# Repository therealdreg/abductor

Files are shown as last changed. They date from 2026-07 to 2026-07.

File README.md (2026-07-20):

# Abductor

An adapter board that lets you run CW312-format (card-edge) targets on the ChipWhisperer CW308 UFO.
Discussion and questions on the NewAE forum: https://forum.newae.com/t/abductor-a-cw312-to-cw308-ufo-adapter-board/6514

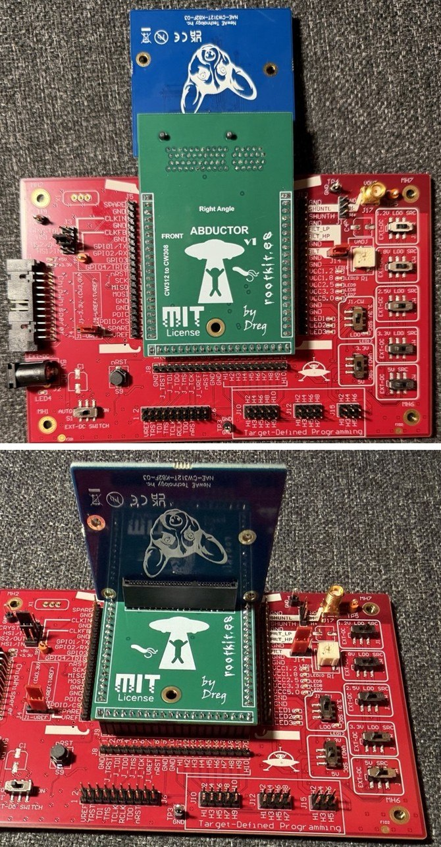
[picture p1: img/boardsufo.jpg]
The Abductor on a CW308 UFO


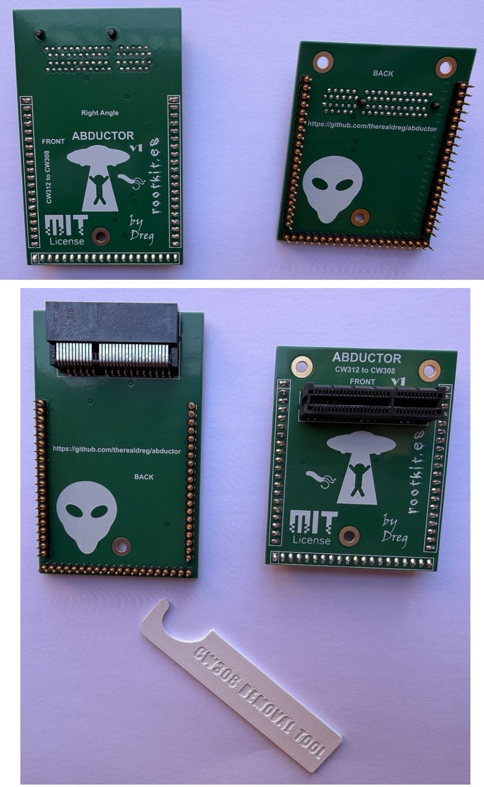
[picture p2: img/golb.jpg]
The Abductor board


There are two versions, one with a right-angle connector and one without. A dedicated target board
designed for one specific use case is usually preferable; when that is not practical, or simply not
possible, this adapter is a low-cost alternative.

Tip: to pull boards off the CW308 UFO without stressing or damaging the PCB, I use a 3D-printed removal
tool: https://github.com/therealdreg/removal_tool_cw308_ufo_chipwhisperer

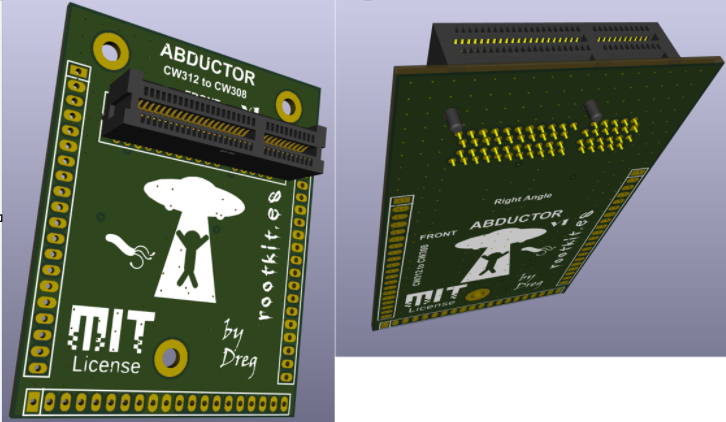
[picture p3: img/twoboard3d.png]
3D renders of the two Abductor variants: straight on the left, right-angle on the right


## Scope and limitations (please read first)

> I am an enthusiast, not a professional hardware or side-channel engineer. This board and its
> documentation are shared in case they are useful to someone, but they may contain mistakes, imprecise
> wording, or design choices a specialist would make differently. Treat everything here as an informal
> engineering log written in good faith, not a datasheet or a qualified test report. Before
> manufacturing the board or depending on it for anything important, review the KiCad source and the
> gerbers yourself. Corrections, reviews and feedback are genuinely welcome.
>
> Every result below comes from a single operator on a single bench, using one physical specimen of each
> board (one unit of each Abductor variant, standard and Right-Angle), one ChipWhisperer Husky Plus, and
> one of each target (CW312T-SAM4S, CW312T-iCE40UP, CW312T-K82F), at chipwhisperer commit `3c8e4347` (see
> the test bench). Most quantitative figures (SNR, TVLA t, |rho|, glitch bypass rates) are single runs
> and carry run-to-run and re-assembly variance that was not independently characterized here unless a
> sample count says otherwise; they are not multi-unit or multi-operator averages. Comparative words used
> throughout ("comparable", "consistent with", "no measurable difference") describe the specific sessions
> recorded here, not a general guarantee about the hardware. Where a result was inconclusive or a method
> was circular, it is flagged as such rather than smoothed over. On the whole, after the broad (if mostly
> single-run) testing below, I consider the electrical design validated for my own use and good enough
> for what I need it to do.

## How it works

The CW308 UFO and the CW312 target family use different physical interfaces. The UFO expects targets on
its 0.1-inch pin-header target sockets, while CW312 boards plug into a card-edge slot. The Abductor
bridges the two: it exposes the UFO target-header footprint on one side and a CW312 card-edge socket on
the other, and handles the signal mapping in between, so a CW312 target that uses the standard card-edge
interface should mount and run on the UFO. For the 1.00 mm CW312 edge the board uses a compatible Samtec
PCIE-series socket (part numbers and rationale are in the bill of materials).

Fitting the UFO theme, the name captures the idea: the UFO abducts the CW312 target and pulls it in so
it can run on the CW308 platform.

## Building the board

Everything needed to fabricate a board: the KiCad sources, the stackup and gerbers, the parts, and a note
on the small target-board trim the straight variant calls for.

### KiCad v10 sources

This is not a KiCad project I work in regularly, so please review the source files before relying on
them for manufacturing. Two plugins are used:

- ViaStitching: https://github.com/dobredanielstelian/ViaStitching (a KiCad 10 port of JS Reynaud's
  via-stitching plugin, `jsreynaud/kicad-action-scripts`)
- easyeda2kicad: install with `pip install easyeda2kicad` (uPesy's tool; output targets KiCad v6+)

The two connector footprints are imported with easyeda2kicad:

```
python -m easyeda2kicad --full --lcsc_id=C4597619 --output "C:\\path\\to\\project" --project-relative --overwrite

python -m easyeda2kicad --full --lcsc_id=C4571870 --output "C:\\path\\to\\project\\right_angle" --project-relative --overwrite
```

(LCSC `C4597619` = Samtec PCIE-064-02-F-D-TH, `C4571870` = Samtec PCIE-064-02-F-D-RA; these match the
bill of materials below.)

### PCB and gerbers

Six layers, ENIG finish. This many signals (power and shunt sensing, the HS2 clock, serial, the
crowbar/VOUT glitch path, the JTAG/SWD debug lines, the trigger, the LEDs and GPIO) route more
comfortably on six layers, which give a continuous ground plane, a power layer split into islands for the
several rails, and shorter return paths. I chose six layers for that routing headroom, not because the
data proves them necessary: at ~7 MHz the signal-integrity upside should
be small, and the A/B comparison in the results below does not show the adapter improving on a direct
connection. Whether four layers would perform the same I cannot say, since I never built one to compare.
I chose ENIG for flat, uniform pads under the 1.00 mm fine-pitch Samtec socket; this board has no
gold-finger edge of its own, so a cheaper HASL finish would most likely also work. I ordered both variants
as six-layer ENIG prototypes from JLCPCB (https://jlcpcb.com/quote), five pieces of each, and the boards
were more than suitable for the testing that follows. They came back to this spec:

| JLCPCB parameter | Value |
|---|---|
| Base material | FR-4, TG135 |
| Layers | 6 |
| Dimensions | 54 mm × 67 mm |
| Thickness | 1.6 mm |
| Outer / inner copper | 1 oz / 0.5 oz |
| Surface finish | ENIG, 1 µin gold (1U″) |
| Solder mask / silkscreen | Green / white, ink-jet |
| Via covering | Epoxy filled and capped |
| Min via | 0.3 mm hole, 0.4 to 0.45 mm diameter |
| Electrical test | Flying-probe, full |
| Appearance quality | IPC Class 2 |
| Outline tolerance | ±0.2 mm |

The value impressed me: for a six-layer, ENIG, flying-probe-tested board ordered in a small five-off
prototype quantity, the quality came out far better than I expected for such an inexpensive low-volume run,
and I was genuinely impressed by what came back.

Schematic: 

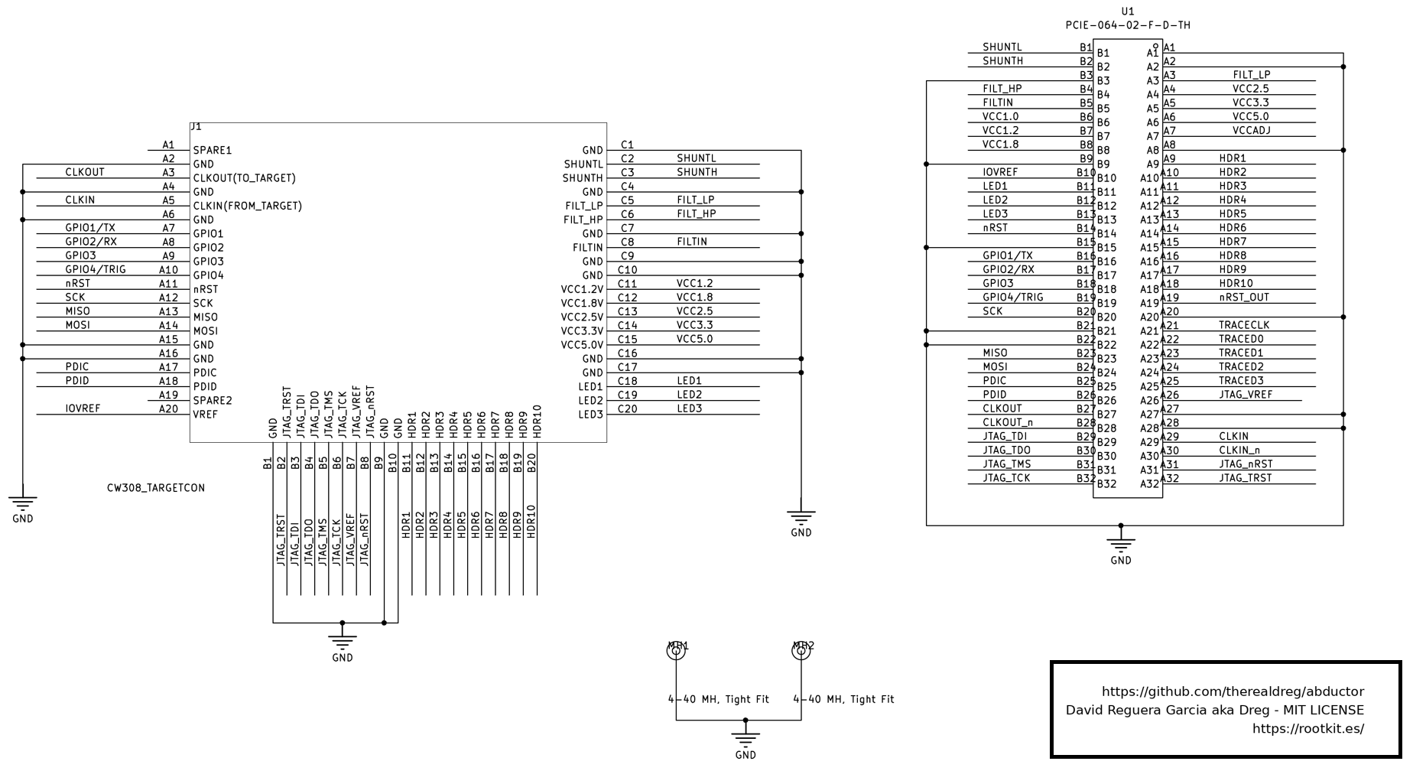
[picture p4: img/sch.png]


Gerbers:

- Straight version: [prj/gerber.zip](prj/gerber.zip)
- Right-angle version: [prj/right_angle/gerber.zip](prj/right_angle/gerber.zip)

### Bill of materials

NewAE does not publish a connector part number for the 1.00 mm CW312 card edge (the CW313 documentation
only calls it the "cost-optimized CW312 card edge connector"), so the parts below are a compatible
selection I chose, not an official NewAE specification.

**Card-edge socket, straight: Samtec PCIE-064-02-F-D-TH.** 1.00 mm pitch, 64-position (mechanically the
length of a PCIe x4 slot), through-hole card-edge socket from Samtec's PCIe-connector series. It is used
here purely for its mechanical fit to the 1.00 mm CW312 card edge; the connector's PCIe signaling rating
is not relevant, since this edge carries DC rails and a ~7 MHz clock, not a PCIe link. Mouser: https://www.mouser.es/ProductDetail/Samtec/PCIE-064-02-F-D-TH?qs=iT52DjcXudu3X3%2FATBSy9g%3D%3D

**Card-edge socket, right-angle: Samtec PCIE-064-02-F-D-RA.** Right-angle version of the same 1.00 mm
pitch, 64-position Samtec card-edge socket (same PCIe-connector series, again used only for mechanical
fit). Mouser: https://www.mouser.es/ProductDetail/Samtec/PCIE-064-02-F-D-RA?qs=92ilVni64gwDtfpZKan9%2FQ%3D%3D

**Male header: Preci-dip 800-10-020-10-001101.** 20-pin, 2.54 mm machined pin strip. Mouser: https://www.mouser.es/ProductDetail/437-8001002010001101

**Female socket strip: Preci-dip 801-87-020-10-001101.** 20-pin, 2.54 mm machined socket strip; the same
20-pin header NewAE specifies for the CW308. Mouser: https://www.mouser.es/ProductDetail/437-8018702010001101

### Target-board clearance (straight variant only)

On the **straight** Abductor, a small corner of the ChipWhisperer CW312 target board fouls the adapter
when the target is seated, so that corner of the **target board** has to be trimmed off. The photos below
show it on a CW312T-K82F target: the corner is nipped with flush cutters and the edge sanded, away from
the target's mounting hole. This is not an Abductor design flaw and cannot be designed out of the adapter,
because the collision is with the official ChipWhisperer target boards, which are fixed products you
cannot redesign; on the straight variant you simply remove that small corner from each target once. It is
a minor, one-time step, not a drama. The **Right-Angle** Abductor does not need it: its right-angle
connector seats the target clear of the adapter, so no target has to be trimmed.

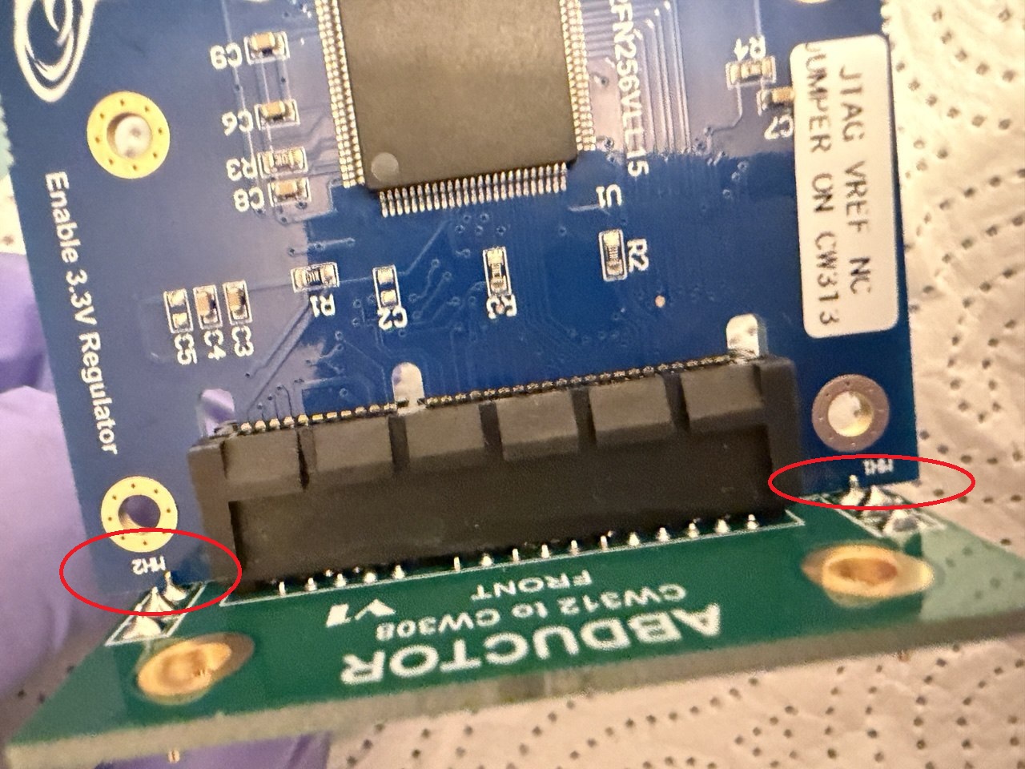
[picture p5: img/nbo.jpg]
The corner of the CW312 target board that fouls the straight Abductor when seated


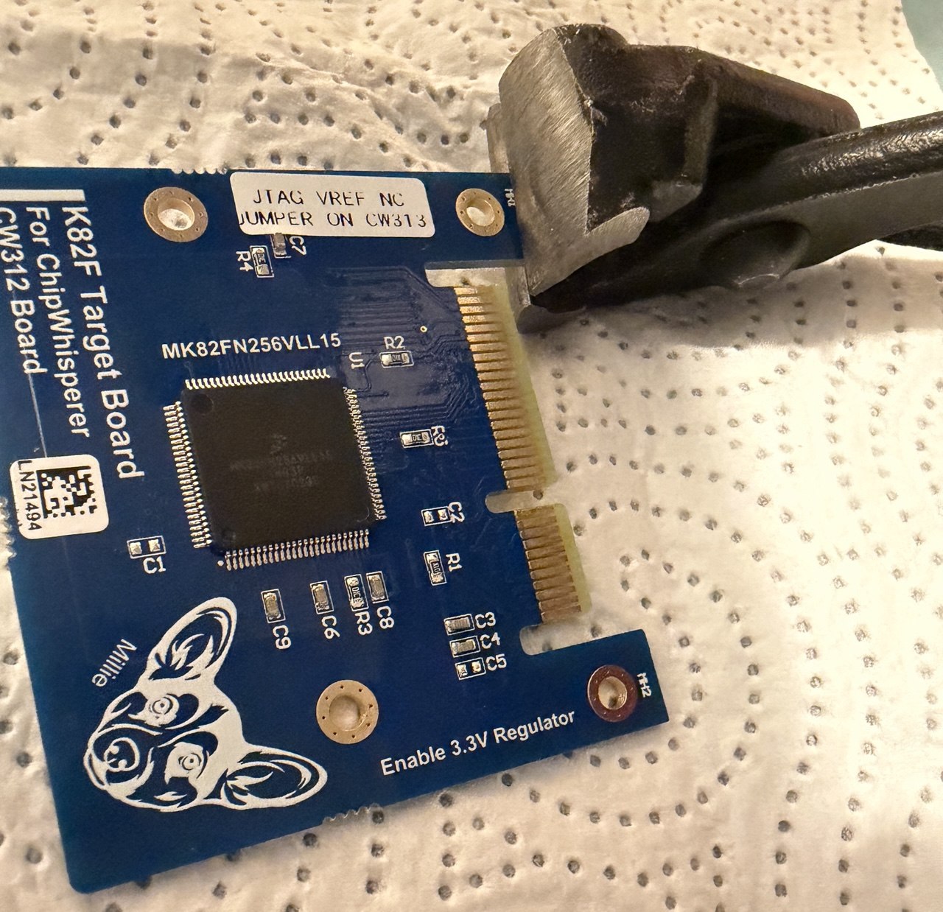
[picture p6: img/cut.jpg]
Trimming that corner off the CW312 target board with flush cutters


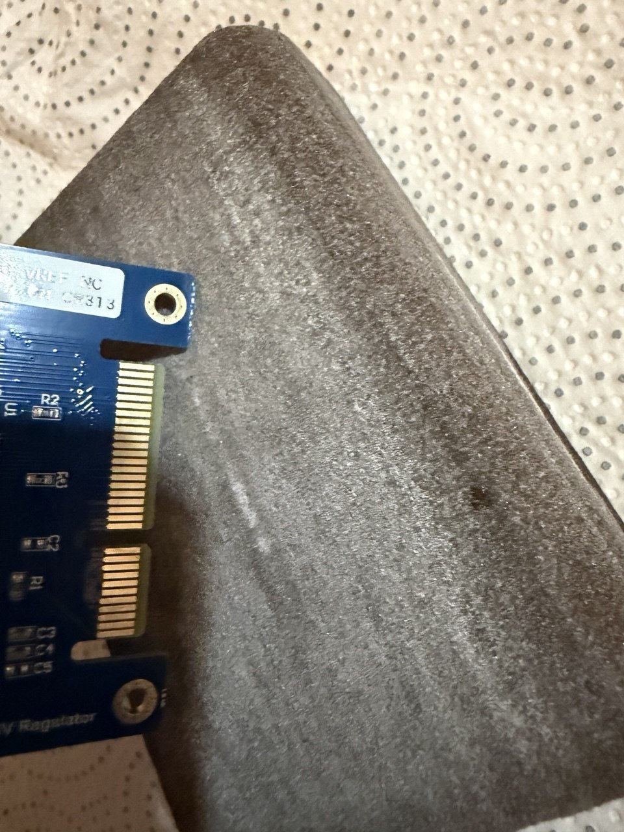
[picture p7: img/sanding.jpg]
The sanded edge of the trimmed target board


This is roughly how much of the target-board corner to remove:

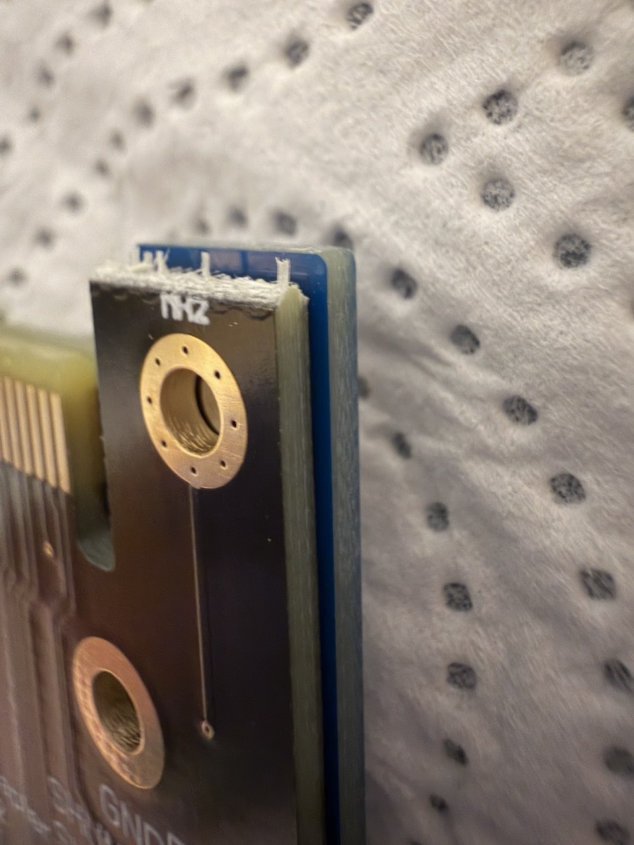
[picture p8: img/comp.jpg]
How much of the target-board corner to remove


---

## ChipWhisperer validation

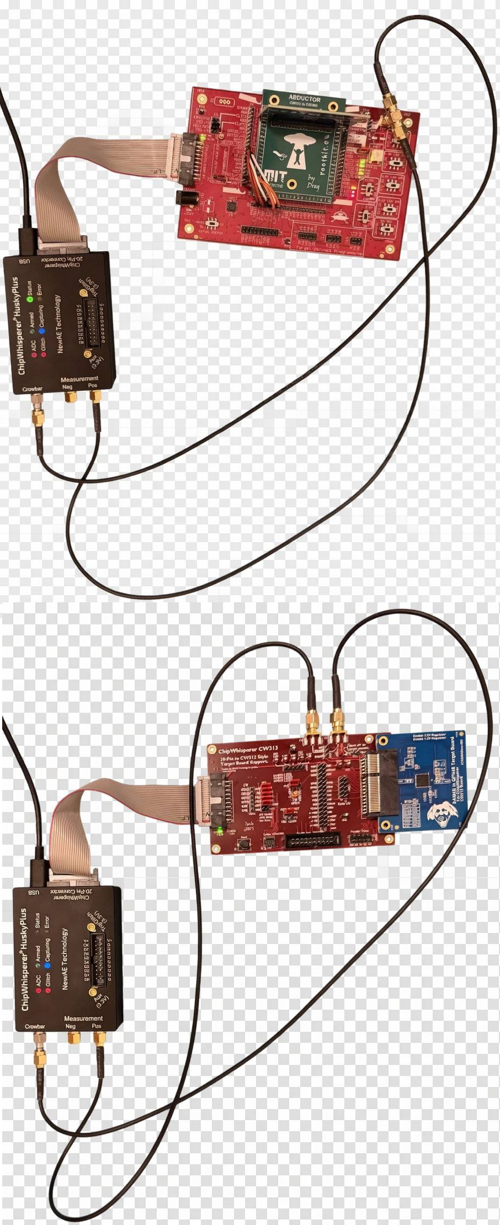
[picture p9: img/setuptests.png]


The rest of this document is my own functional testing of the board on real ChipWhisperer hardware, run
one demo at a time through the adapter. The aim is to show that the adapter carries the signals each demo
needs and produces valid side-channel data, not to reproduce the reference notebooks pixel for pixel.
Please read the scope and limitations above before taking any number as more than a single-bench
observation.

- **Date:** 2026-07-18 (standard Abductor, iCE40, K82F); 2026-07-19 (Right-Angle variant).
- **Setup under test:** the **standard Abductor** and, separately, the **Right-Angle** variant, each on
  the CW308 UFO with a CW312T-SAM4S target and a Husky Plus (the full bench is tabulated below).
- **Method:** one demo at a time, each verified before moving on, following the course order starting
  with `sca101`.

## Test bench

Every number in this document comes from this one bench: the hardware below, driving the software
environment below.

| Hardware | Detail |
|---|---|
| Capture | ChipWhisperer **Husky Plus**, USB `2b3e:ace6`, SN `50203220573555303230333230313036` |
| Husky firmware | FW `1.2.0`, FPGA build `2026-05-22 12:13` |
| Carrier | CW308 **UFO** |
| Adapter | **Abductor** CW312 to CW308, **standard variant (non-right-angle)** |
| Target | **CW312T-SAM4S** (Microchip / ex-Atmel SAM4S, ATSAM4S2, Arm Cortex-M4 without FPU), `PLATFORM=CW312_SAM4S` |
| Target clock | `scope.default_setup()` requests 7.37 MHz on HS2 (`scope.io.hs2='clkgen'`); the Husky's clock generator produces 7.363636 MHz (consistent with the `adc_mul=4` ADC rate 29.454545 MHz) |
| ADC | 29.454545 MHz (`adc_mul=4`), 12 bit |

HS2 is the ChipWhisperer high-speed clock output; on the CW308 it reaches the target CLKIN through the
UFO's clock routing.

| Software | Version / value |
|---|---|
| OS | **Ubuntu 26.04 LTS**, kernel `7.0.0-28-generic`, x86_64 |
| chipwhisperer repo | branch `develop`, commit **`3c8e4347507376d88f2e072fd39df28b380dd713`** (`3c8e4347`, 2026-06-17) |
| commit subject | `Wait after setting trace/UARTTtrigger.fe_clock_src` |
| `jupyter` submodule (notebooks) | `fe7e2aa1585798c3a5a6b247f231abe2e2b4a2cd` |
| chipwhisperer package | `6.0.0` (editable install) |
| Python (venv) | `3.12.13`, created with `uv 0.11.29` |
| Python (system) | `3.14.4`, not used because `numpy 1.26.4` ships no 3.14 wheels and did not build from source in this environment |
| numpy | `1.26.4` |
| ARM toolchain | xpack `arm-none-eabi-gcc 13.3.1` |
| SimpleSerial | `SS_VER_1_1` (firmware default for the base target) |
| SAM4S programmer | SAM-BA (`cw.programmers.SAM4SProgrammer`, erase pin `pdic`) |

## Results summary: Abductor vs Right-Angle vs CW313

The same test suite was run through three setups with the same CW312T-SAM4S target and Husky Plus: the
standard **Abductor** (Husky -> CW308 UFO -> Abductor -> SAM4S), a second **Right-Angle Abductor**
hardware variant, and the SAM4S in its native **CW313** baseboard directly (no adapter). The **Abductor
RA** column is that right-angle variant: its PCB traces run a little longer and are routed differently,
so it is a useful check that the extra routing does not degrade anything. Two further targets, a
**CW312T-iCE40UP** FPGA and a **CW312T-K82F** hardware crypto accelerator, were also run through every
setup as completely different target classes; each non-SAM4S target was moved from the Abductor into the
CW313 directly for its reference run.

Abductor evidence is in `validation/img/` and the `*_dump.txt` files; the CW313 reference is in
`validation/img/cw313/`, `validation/img/*_cw313.png` and `*_cw313_dump.txt`. Every capture script accepts
a `cw313` argument to reproduce the reference run.

| Test | Metric | Abductor | Abductor RA | CW313 direct | Verdict |
|---|---|---|---|---|---|
| Bring-up | traces / serial echo | 10/10 · 10/10 | 10/10 · 10/10 | 10/10 · 10/10 | same |
| Bring-up | mean power p2p | 0.57 | 0.68 | 0.62 | ~same |
| CPA (AES) | full key | yes | yes | yes | same |
| CPA | traces to rank 0 (single run) | 30 | 30 | 30 | same (see note) |
| DPA (AES) | full 16-byte key | yes | yes | yes | same |
| Password SPA | recovered | `h0px3` | `h0px3` | `h0px3` | same |
| Password SPA | winner margin | 22x to 24x | 23x to 25x | 23x to 24x | comparable |
| SNR | peak (linear / dB) | 14.1 / 11.5 dB | 14.0 / 11.5 dB | 16.7 / 12.2 dB | CW313 ~18% higher (linear); single estimate each, small degradation not excluded |
| TVLA | max \|t\| (threshold 4.5) | 60.7 | 59.5 | 60.7 | comparable |
| GPIO3 | TIO3 toggles | yes | yes | yes | same |
| SWD debug | DPIDR / Chip ID | `0x2ba01477` / `0x288b07e1` | `0x2ba01477` / `0x288b07e1` | `0x2ba01477` / `0x288b07e1` | identical |
| Full JTAG | TAP IDCODE | `0x4ba00477` | `0x4ba00477` | `0x4ba00477` | identical |
| Voltage glitch HP | optimum (width, offset, ext) | (1950, 2480, 129) | (2000, 2450, 129) | (1950, 2460, 129) | same ext (129); offset differs by ~1 step |
| Voltage glitch HP | bypass rate | 49.5% (200-shot batch) | 90% (36/40 peak, 40 shots) | 40.5% (200-shot batch) | bypasses on all paths (RA is a 40-shot peak, not directly comparable to the 200-shot batch rates; the standard Abductor's comparable peak is 78% to 98%, see Fault injection) |
| Voltage glitch LP | crash vs repeat | rep1 clean, rep>=2 crash | rep1 clean, rep>=2 crash | rep1 clean, rep>=2 crash | same threshold |
| Clock glitch | faults the SAM4S | yes | yes | yes | same |
| LED1/2/3 | blink in sequence | yes | yes | yes | same |
| Memory dump | crowbar send-loop | 601-byte @ (2000, 2480, 2122) | 510-byte @ (1900, 2200, 88), secret leaked | 510-byte @ (2000, 2480, 2122) | same class of fault (probabilistic point; dump length varies) |
| iCE40 AES | known-answer `AES(0,0)` | `66e94bd4...` | `66e94bd4...` | `66e94bd4...` | identical |
| iCE40 CPA | traces to full key | 3000 | 3000 | 3000 | same (single-run convergence) |
| iCE40 TVLA | max \|t\| (threshold 4.5) | 85.0 | 85.8 | 89.3 | comparable |
| iCE40 DFA | full key (round-8, phoenixAES) | 16/16 | 16/16 | 16/16 | same |
| K82F KAT | `AES(2b7e..,00..0f)` | `50fe67cc...` | `50fe67cc...` | `50fe67cc...` | identical |
| K82F TVLA | max \|t\| (threshold 4.5) | 100.6 | 96.0 | 65.8 | all ≫ 4.5 at 8k traces each (large single-run spread) |
| K82F CPA | byte-0 leakage \|rho\| | ~0.10 | ~0.10 | ~0.10 (0.095) | ~same (each \|rho\| has SE ~0.005; the exact tie is coincidental) |
| K82F CPA | full AES key | not recovered (1/16, rigorous disjoint-set) | not recovered (0/16) | not recovered (0/16) | consistent with target, not adapter (single control run; the 1/16 is at most one byte, not a full-key break) |

Verdict key: *identical* = bit/value-exact match for fixed digital quantities (IDCODEs, KATs). *~same* =
point estimates whose difference is within (or smaller than) the available scatter, so a small effect is
neither confirmed nor excluded (SNR, |rho|, p2p). *comparable* = same order of magnitude, differences
consistent with run-to-run variation (TVLA t, margins). *same* = same qualitative pass/fail. Two
result-specific notes on the table: *traces to rank 0* is a single-run, data-dependent convergence count
on a coarse trace grid, not a bit-exact constant and not a guessing-entropy average; it landed at 30 on
all three paths here but can vary run-to-run (see Side channel). For *K82F full AES key*, the mmCAU is an
unprotected accelerator that first-order CPA did not break on any path; the single byte recovered under
the rigorous criterion on the Abductor (1/16, vs 0/16 on the other two) is a marginal one-byte result at
the edge of the method's sensitivity, not a full-key break (see the K82F target).

**Conclusion.** Within this setup and test set, no test resolved a difference between the Abductor and
the SAM4S running directly in a CW313 baseboard beyond single-run scatter, the one exception being the
SNR point estimate, which was in fact slightly *higher* on the direct CW313 path (16.7 vs 14.1 linear;
about 0.7 dB). So this run gives no evidence that the Abductor improves the signal, and with one estimate
per path a small degradation cannot be excluded either (see Signal coverage and integrity). Otherwise the
adapter carried the demonstrated portion of the suite (side channel, fault injection, debug, I/O) with
results consistent with the direct connection: CPA recovers the full key in the same 30 traces; TVLA
max |t| came out at 60.7 on both paths (an exact match to three significant figures that is coincidental,
see Signal coverage and integrity); the fixed debug IDs match bit-for-bit; the glitch optimum lands at the same
ext_offset (129); the 200-shot bypass rates (49.5% Abductor, 40.5% CW313) differ by less than the
measurement can resolve (see Fault injection); and the memory-dump fault lands at the same parameters.
The **Right-Angle** variant behaved the same way, reproducing every key outcome despite its longer,
differently-routed traces (SNR 14.0 vs 14.1, TVLA 59.5 vs 60.7, CPA full key in the same 30 traces,
matching DPIDR and JTAG IDCODE, glitch at the same ext_offset 129, and a memory dump that leaked the
secret). The two other targets stretch the range further: through the Abductor, the iCE40 FPGA fell to
both a hardware-AES CPA and a full `phoenixAES` DFA, while the K82F mmCAU accelerator resisted the
first-order CPA tried here on every path alike. Per-test detail and evidence follow below.

## Primary target: CW312T-SAM4S

The SAM4S is the primary target and gets the deepest workout: a bring-up smoke test, the full `sca101`
side-channel walkthrough, `fault101` voltage and clock glitching, a JTAG/SWD debug takeover, and a
pin-by-pin coverage and signal-integrity check. Each subsection exercises a different set of signals the
Abductor has to route.

### Bring-up: signal chain validation

A smoke test that builds `simpleserial-base`, flashes it over SAM-BA, and captures traces. Each row
exercises a distinct path the Abductor has to route. Script: `validation/scripts/smoke_bringup.py`.

| # | Test | Abductor path exercised | Status | Metric |
|---|---|---|---|---|
| 0 | Connect to Husky Plus | n/a (scope only) | ✅ | `cwhuskyplus`, FW 1.2.0 |
| 1 | Build SAM4S firmware | n/a (host build) | ✅ | `simpleserial-base-CW312_SAM4S.hex`, ROM 2.17% of 128 KB |
| 2 | Flash over SAM-BA (ERASE=`pdic`, `nrst`) | control and reset lines | ✅ | program plus verify OK in 5.0 s |
| 3 | Bidirectional UART (echo of `p` command) | serial TX and RX | ✅ | 10/10 echoes correct |
| 4 | Trigger and capture | trigger and sync | ✅ | 10/10 traces, 5000 samples each |
| 5 | Clock and power measurement | HS2 clock plus shunt/SMA | ✅ | mean per-trace p2p 0.57, global sample std 0.14, clean clock cycles |

The Abductor routed clock, power, serial, ERASE and NRST correctly in this run. The full signal chain
(Husky Plus -> CW308 UFO -> Abductor -> SAM4S) is operational.

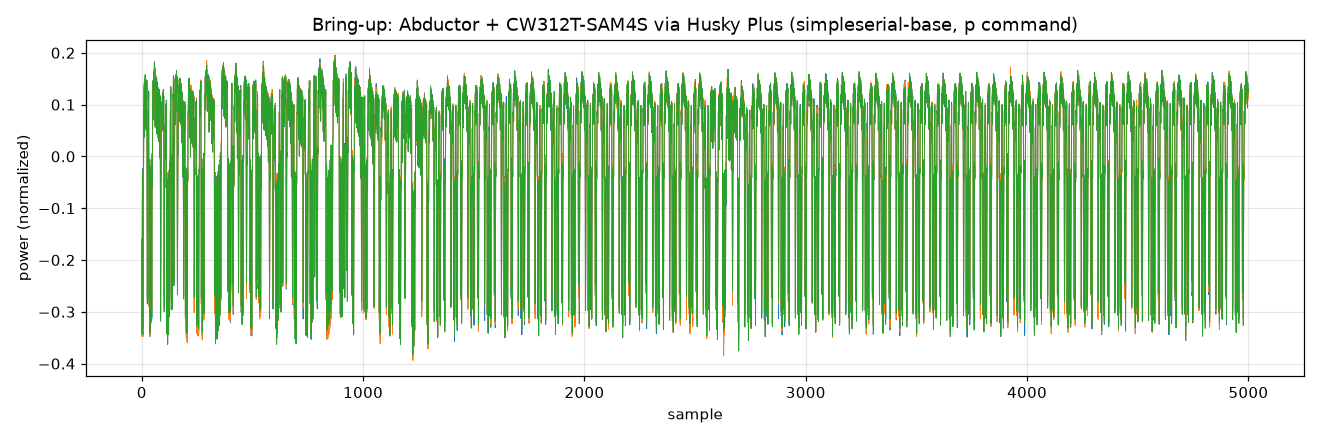
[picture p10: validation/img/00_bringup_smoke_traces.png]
Bring-up power traces


### Side channel (sca101 walkthrough)

The `sca101` course builds up from timing to a full AES key recovery. Every hardware lab passed; the
software-only labs are skipped and marked as such.

| Lab | Title | Firmware | Status |
|---|---|---|---|
| 2_1A | Instruction Power Differences | simpleserial-base | ✅ Pass |
| 2_1B | Power Analysis for Password Bypass | basic-passwdcheck | ✅ Pass |
| 3_1 | Large Hamming Weight Swings | simpleserial-aes (TINYAES128C) | ✅ Pass |
| 3_2 | Recovering Data from a Single Bit | n/a | ⏭️ Skipped (software-only, no hardware) |
| 3_3 | DPA on a Firmware AES Implementation | simpleserial-aes (TINYAES128C) | ✅ Pass (full key) |
| 4_1 | Power and Hamming Weight Relationship | n/a | ⏭️ Skipped (low-impact stepping stone) |
| 4_2 | CPA on a Firmware AES Implementation | simpleserial-aes (TINYAES128C) | ✅ Pass (full key, 30 traces) |
| 4_3 | ChipWhisperer Analyzer CPA Attack | simpleserial-aes | ⏳ Pending |
| 5_1 | ChipWhisperer CPA Attacks in Practice | simpleserial-aes | ⏳ Pending |
| 6_4 | Jittery Triggering on UART | simpleserial-base | ⏳ Pending |

Legend: ✅ pass · ⏳ pending · ⚠️ pass with notes · ❌ fail · ⏭️ skipped (not a hardware test)

#### Lab 2_1A: Instruction Power Differences

Different instruction blocks were inserted between `trigger_high()` and `trigger_low()` in
`simpleserial-base`, then built, flashed and captured. The execution cost of each block is read directly
from the trigger duration (`scope.adc.trig_count`). This counter is in ADC samples, and with `adc_mul=4`
there are 4 samples per core clock cycle, so the counts below are ADC samples (roughly 4x the core-cycle
count), not core cycles. Script: `validation/scripts/lab_2_1A.py`.

| Instruction block | Trigger duration (ADC samples) | Cost vs baseline |
|---|---|---|
| baseline (empty) | 492 | reference |
| 20x `A *= 2` (unrolled multiply) | 992 | +500 (about 25 ADC samples, ~6 core cycles, per volatile statement) |
| loop x20 `A *= 2` (multiply) | 2132 | +1640 (about 82 ADC samples, ~20 core cycles, per iteration) |
| loop x20 `A /= 3` (integer divide, multi-cycle) | 2276 | +1784 (144 more than the multiply loop) |

Findings:

- The sample count was identical across all 15 captures (min equals max), as expected for a
  deterministic trigger counter, and consistent with the count being read back without corruption
  through the Abductor.
- The unrolled block adds a flat per-statement cost. The looped version costs far more than unrolling the
  same 20 multiplies; the extra cost is consistent with per-iteration loop overhead (the volatile counter
  load/store, compare and branch), though this measurement records only the total trigger duration and
  does not isolate those components individually.
- The divide loop is more expensive than the multiply loop. Here `A` is a `volatile long int`, so
  `A /= 3` is integer division, which is more work than the multiply either way: depending on the build
  optimization the compiler emits the multi-cycle Cortex-M4 `SDIV`, or, for a constant divisor like 3, a
  strength-reduced multiply-and-shift sequence. This measurement records only the total trigger duration
  and cannot distinguish the two, so it does not prove an `SDIV` executed; the higher cost is simply
  consistent with integer division costing more than the multiply.

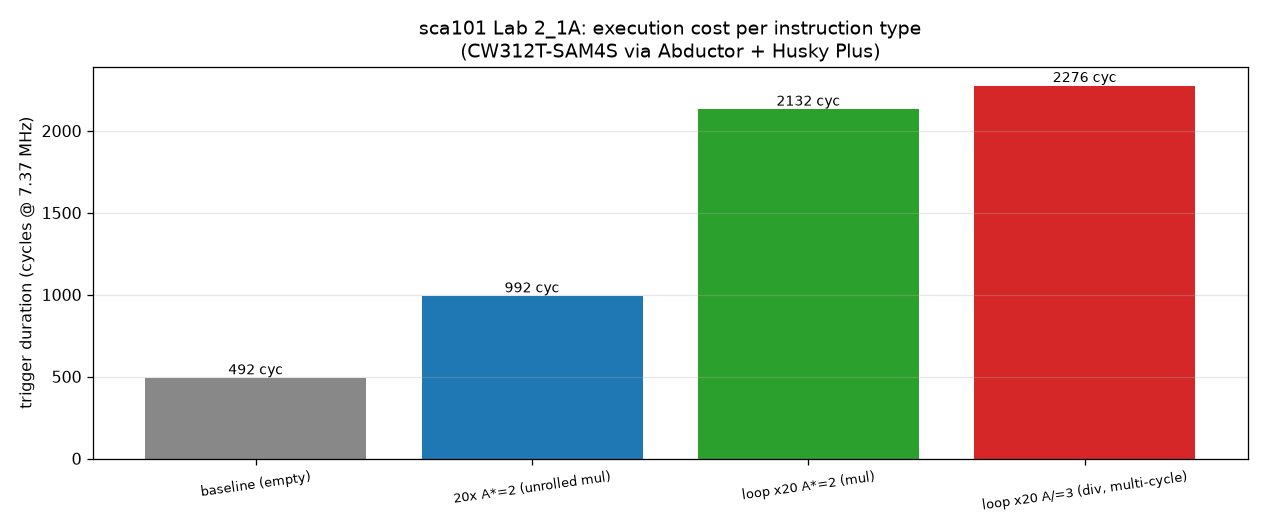
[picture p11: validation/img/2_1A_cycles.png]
Execution cost per instruction type


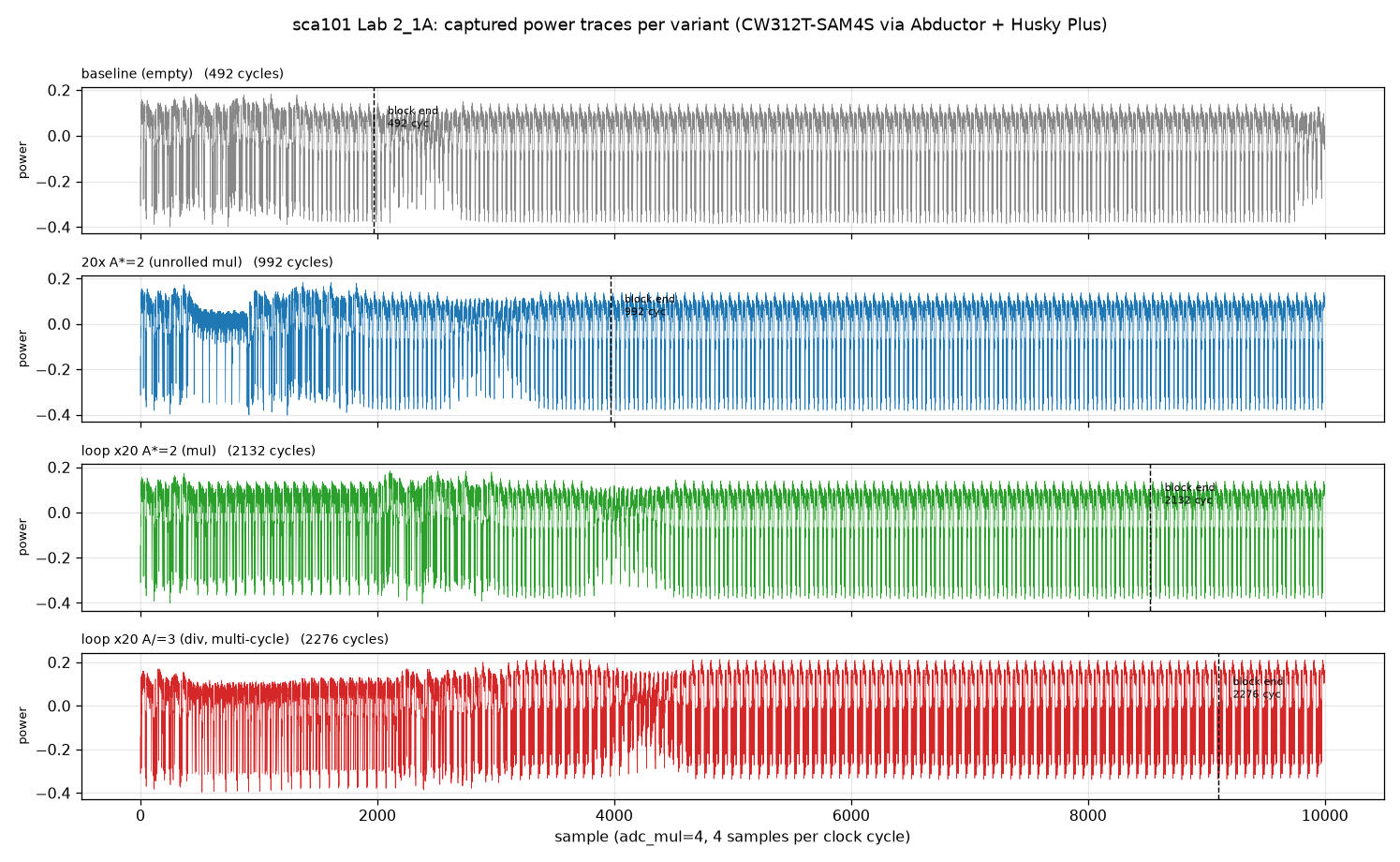
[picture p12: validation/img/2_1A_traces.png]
Captured power traces per variant


#### Lab 2_1B: Power Analysis for Password Bypass

`basic-passwdcheck` checks a fixed password (`h0px3`) one character at a time and bails on the first wrong
character. Each correct character runs one extra loop iteration, so the power trace stays active longer
before diverging. The attack captures one trace per candidate, scores it against a wrong reference with
SAD (sum of absolute differences), keeps the highest scoring character, then repeats for the next
position using the known prefix. Script: `validation/scripts/lab_2_1B.py`.

| Position | Recovered char | SAD (winner) | SAD (2nd best) | Margin |
|---|---|---|---|---|
| 0 | `h` | 286.6 | 11.9 | 24.0x |
| 1 | `0` | 284.6 | 12.4 | 22.9x |
| 2 | `p` | 280.3 | 12.7 | 22.1x |
| 3 | `x` | 274.5 | 12.4 | 22.1x |
| 4 | `3` | 301.7 | 12.3 | 24.4x |

Recovered password: **`h0px3`**, which matches the firmware constant. (Margins are computed from the
full-precision SAD values, so they may differ slightly from dividing the rounded columns shown here.)

The correct character wins each position by roughly 22x to 24x in SAD, a large and easily separable margin
on these single-trace-per-candidate captures. The divergence figure shows the correct and wrong
first-character traces overlapping until the compared byte, then splitting cleanly around sample 420. The
heatmap shows one bright cell per position, spelling out the password.

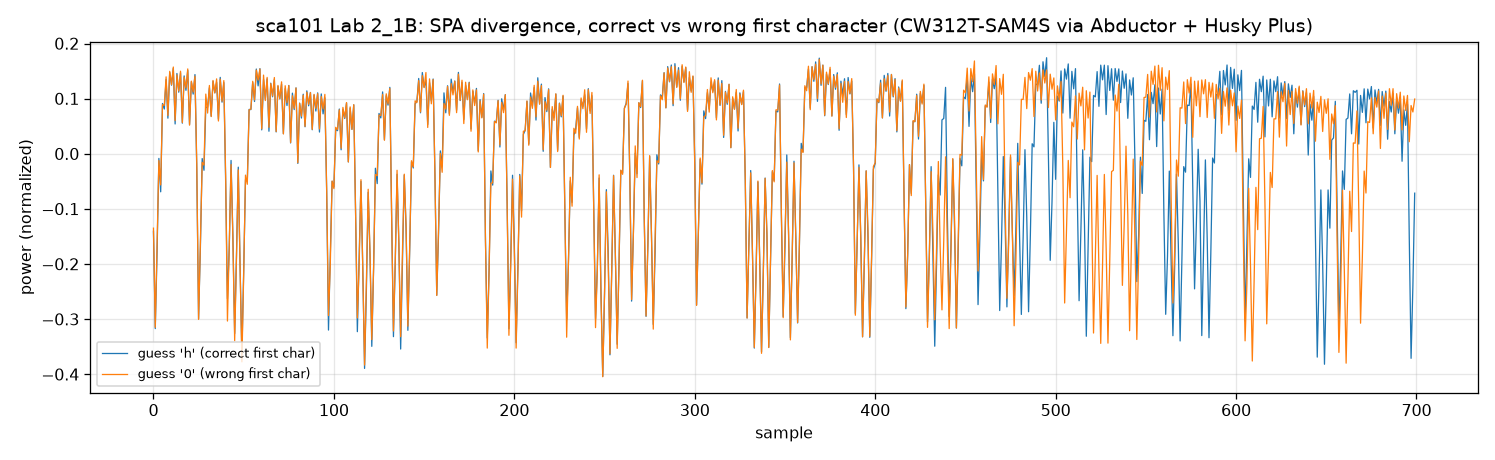
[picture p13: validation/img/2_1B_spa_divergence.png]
SPA divergence, correct vs wrong first character


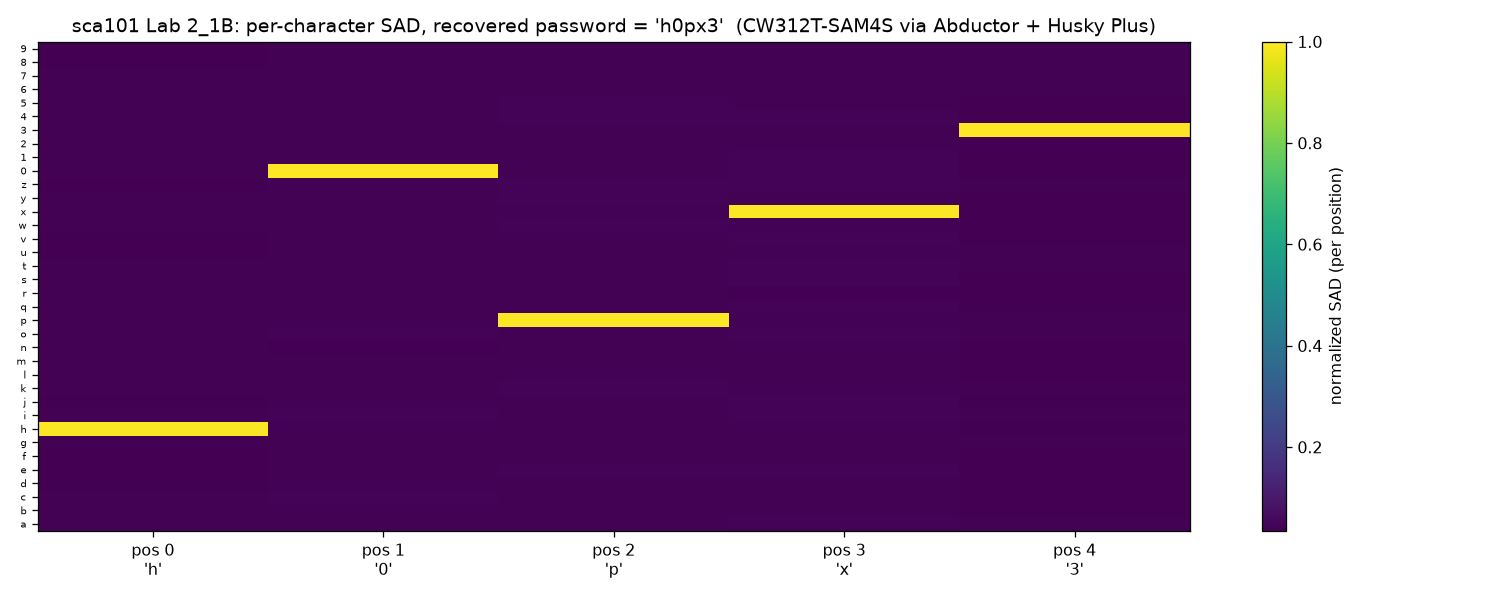
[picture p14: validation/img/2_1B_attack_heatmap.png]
Per-character SAD heatmap with the recovered password


#### Lab 3_1: Large Hamming Weight Swings

This lab shows the target's power depends on the data it manipulates, not only on the code path. With
`simpleserial-aes` (TINYAES128C) running a fixed key, 200 traces were captured while forcing plaintext
byte 0 to either `0x00` (Hamming weight 0) or `0xFF` (Hamming weight 8). In the script each trace's byte 0
is set to `0xFF` or `0x00` according to the parity of the original random byte, which gives a roughly even
split. Averaging each group and subtracting gives the data-dependent leak. Script:
`validation/scripts/lab_3_1.py`.

| Metric | Value |
|---|---|
| Traces | 200 (~100 at 0x00, ~100 at 0xFF, split by the parity of the random byte 0) |
| Peak difference | 0.0254 in magnitude at sample 528 (the value is negative, see the sign note below) |
| Noise floor (std of the difference trace away from the peak) | 0.0008 |
| Leak vs noise | peak difference ~32x the off-peak difference-trace std (informal single-run ratio, not an SNR) |

The difference of means is flat everywhere except a sharp spike at sample 528, where the target loads and
processes that byte. The spike is negative because ChipWhisperer measures across a shunt, so more power
reads as lower voltage, and `0xFF` (more bits set) draws more power than `0x00`. This is the same class of
data-dependent, Hamming-weight leakage that CPA on AES exploits (there through the Hamming weight of the
S-box output, `HW(SBox(pt XOR key))`, rather than the plaintext byte itself).

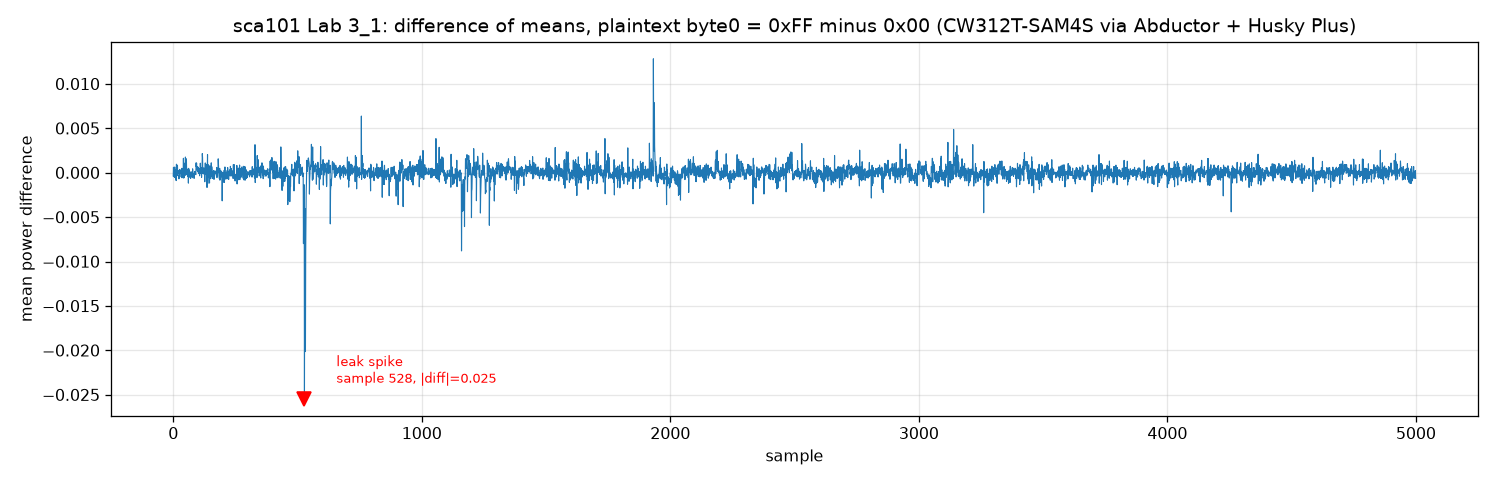
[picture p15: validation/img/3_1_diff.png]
Difference of means, 0xFF minus 0x00


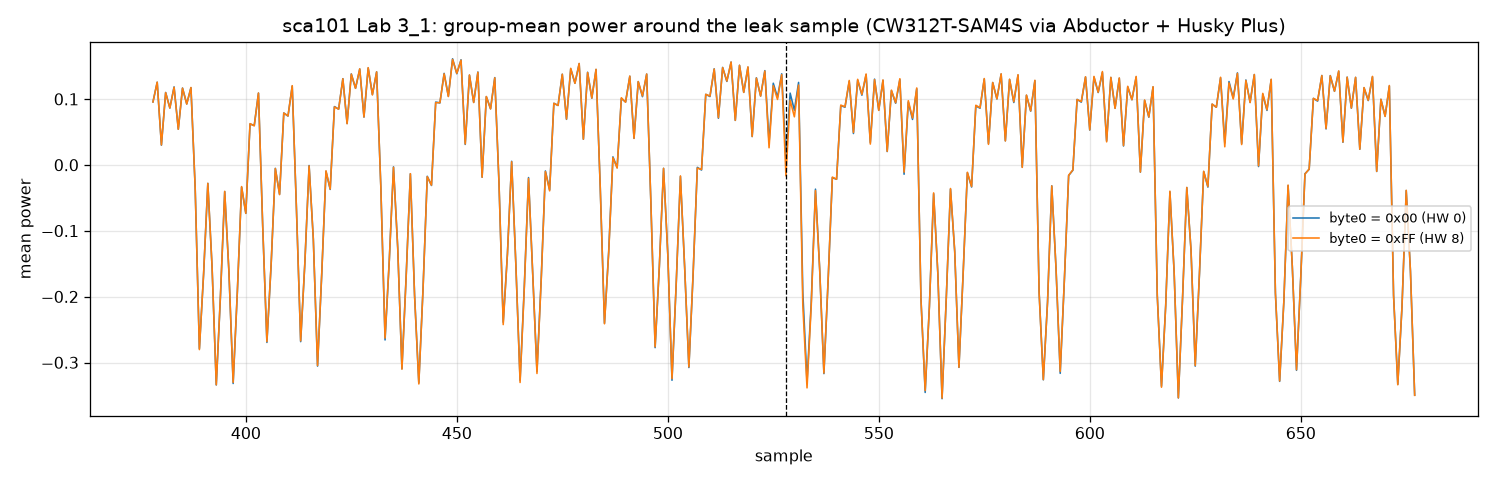
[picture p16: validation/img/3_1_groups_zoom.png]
Group-mean power around the leak sample


#### Lab 3_3: DPA on a Firmware AES Implementation

This is the first full key recovery in the suite: the complete AES-128 key was recovered from the captured
power traces. With `simpleserial-aes` (TINYAES128C) and a fixed key, 2500 traces were captured (about
119 traces/s) while sending random plaintexts. For each key byte and each of the 256 guesses, the traces
are split by bit 0 of `SBox(plaintext_byte XOR key_guess)` and the difference of the two group means is
computed. The guess whose difference-of-means trace peaks highest is taken as the key byte. Script:
`validation/scripts/lab_3_3.py`.

- Traces: 2500 (fixed key, random plaintext)
- Recovered key: `2b7e151628aed2a6abf7158809cf4f3c`
- Known key: `2b7e151628aed2a6abf7158809cf4f3c`
- Full key match: **yes, all 16 bytes**

For every byte the correct guess peak sits above the best wrong guess. For key byte 0 the correct guess
`0x2b` produces a sharp peak near sample 1900 while wrong guesses stay in the noise. The winner margin is
modest because single-bit DPA is noisier than CPA; the CPA lab below improves on this.

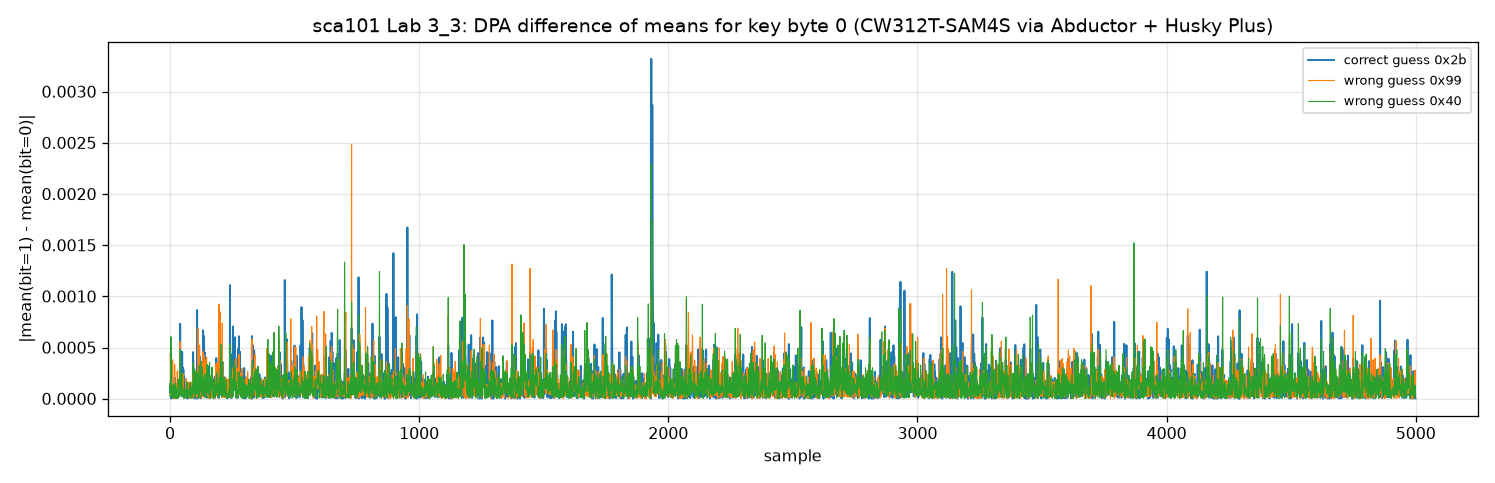
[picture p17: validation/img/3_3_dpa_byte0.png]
DPA difference of means for key byte 0


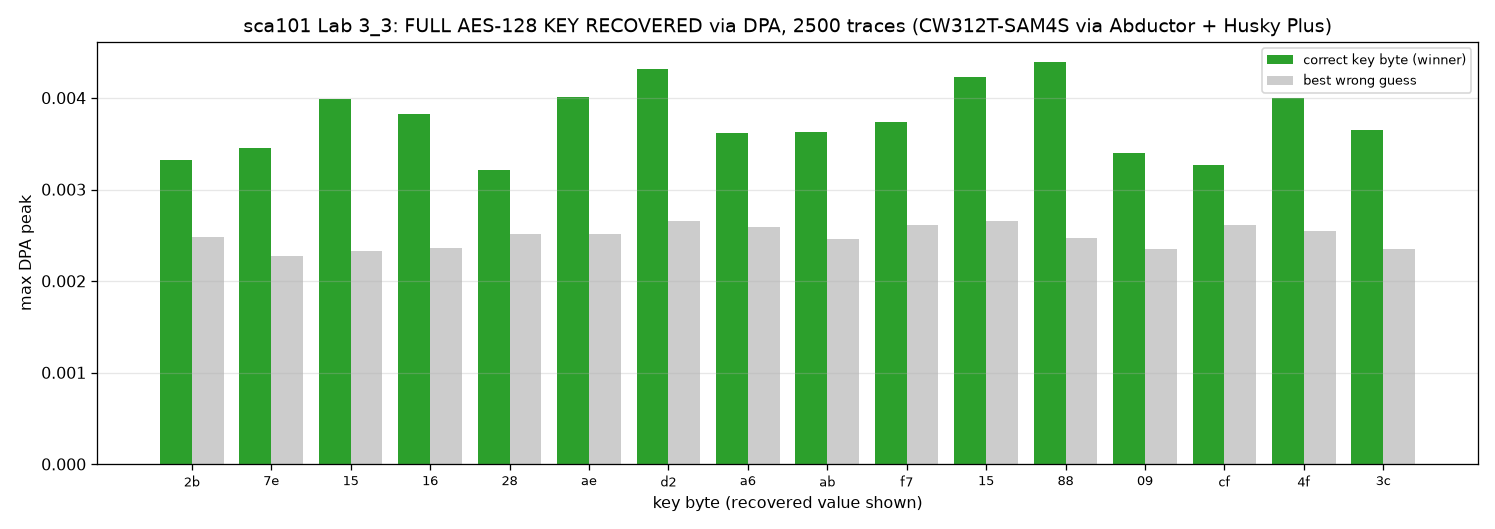
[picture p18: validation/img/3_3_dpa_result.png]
Full key recovered, winner vs best wrong guess per byte


#### Lab 4_2: CPA on a Firmware AES Implementation

Correlation Power Analysis is the stronger attack here because it is less noisy than the single-bit DPA
above. The model is `HW(SBox(plaintext_byte XOR key_guess))`, and for each key byte the guess whose model
has the highest Pearson correlation with the traces is the key byte. Script: `validation/scripts/lab_4_2.py`.

- Traces captured: 1000 (about 120 traces/s)
- Recovered key: `2b7e151628aed2a6abf7158809cf4f3c` (full 16-byte match)
- Correct-byte correlation: about 0.92 to 0.94 in this single 1000-trace run (a single-run point estimate
  that will vary with target and setup)
- Best wrong guess: about 0.20 to 0.31; the correct byte leads the best wrong guess by roughly 0.6 to 0.7
  in absolute |rho|, a wide and unambiguous separation
- Full key first recovered at **~30 traces**: the first grid point where the rank of each of the 16 subkey
  bytes reaches 0 on this single run (coarse trace grid: ...,20,30,40,...). As a single run, not an average
  over many, treat ~30 as an indicative figure, not an averaged guessing-entropy result.

CPA is much cleaner than the single-bit DPA: the correct key stands about 0.6 to 0.7 higher in |rho| than
the best wrong guess, and the whole key falls in a handful of traces. The convergence plot shows the rank
of the correct key dropping to zero by 30 traces.

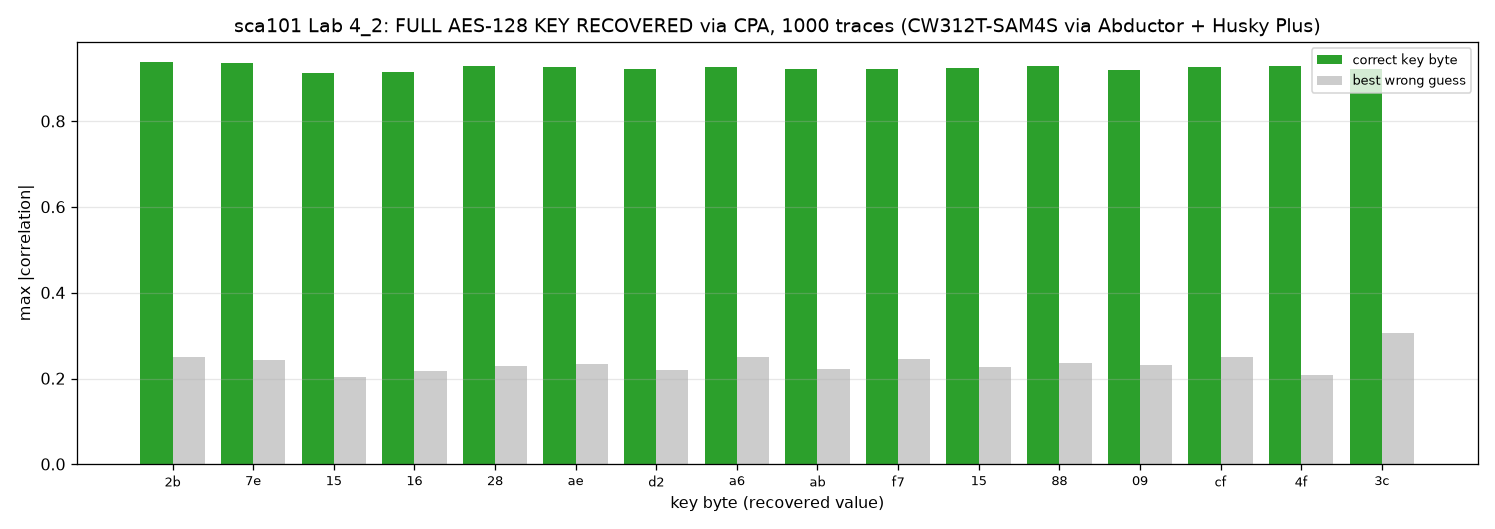
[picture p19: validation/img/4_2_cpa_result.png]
CPA correlations, correct vs best wrong guess per byte


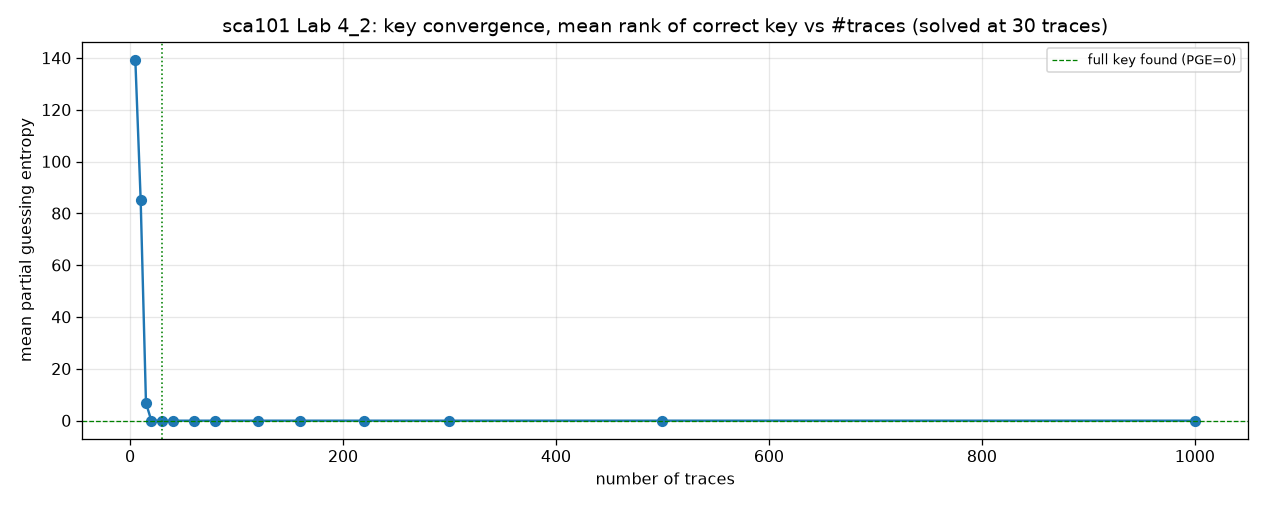
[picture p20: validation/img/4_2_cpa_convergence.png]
Key convergence, correct-subkey rank vs number of traces


### Fault injection (fault101)

For glitching, the Husky CROWBAR SMA and the MEASURE SMA are both tee'd onto the UFO VOUT node
(voltage-glitch wiring, UFO otherwise at stock jumpers). This exercises the Abductor's crowbar and VOUT
path, a different set of signals from the power measurement used above. All SMA cables used throughout are
the stock cables that ship with the ChipWhisperer Husky Plus and the CW313.

#### Fault 2_2: Voltage Glitching to Bypass a Password Check

`simpleserial-glitch` checks a fixed password ("touch"). Sending a WRONG password (`[0]*5`) normally
returns passok=0. A high-power crowbar voltage glitch during the compare loop can leave passok=1, so the
wrong password is accepted, an authentication bypass. Setup: `scope.vglitch_setup('hp')` with
`scope.io.vglitch_reset()` after each attempt. Script: `validation/scripts/fault_2_2_vglitch_bypass.py`.

- Result: **12 password bypasses in 2964 attempts (about 0.4%)**, wrong password accepted as valid.
- Recurring (12 successes across the run) and tightly localized: **ext_offset 129**, glitch offset 2460 to
  2500, width 1900 to 2140.
- The window is a single ext_offset value, which is why a coarse sweep misses it. Voltage glitching is
  probabilistic and this low rate is expected; it may be narrowed further by the shared VOUT tee and SMA
  cabling, though that was not measured.

The target was faulted through the Abductor crowbar path, so that routing carried the crowbar signal.

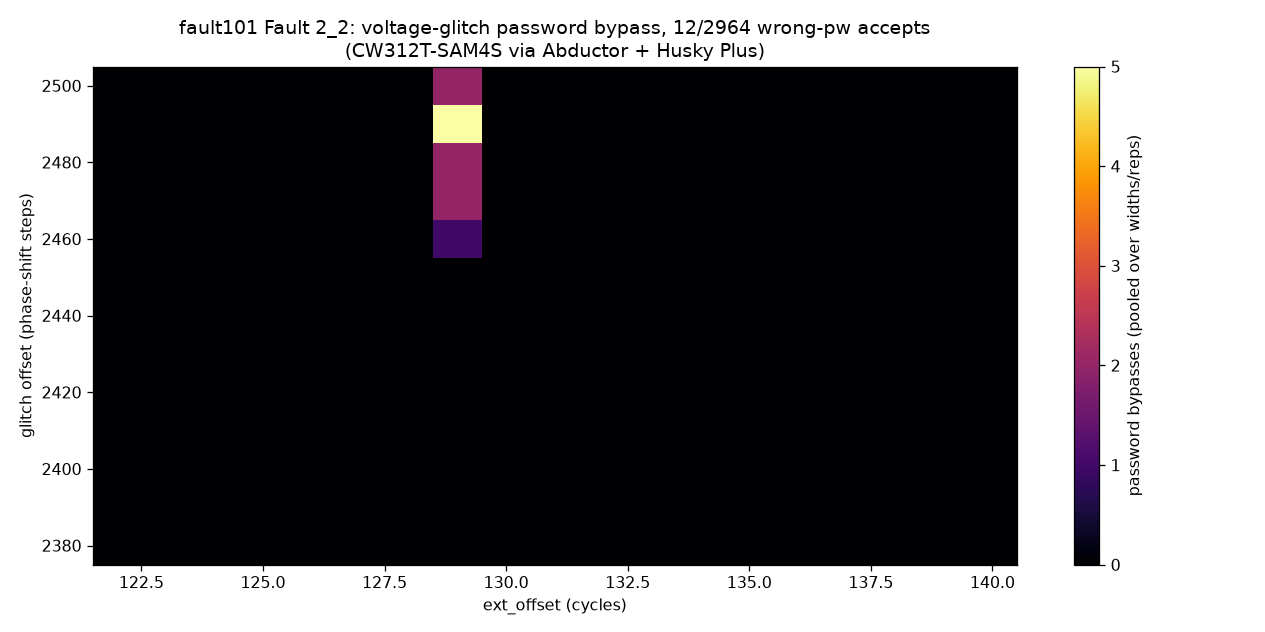
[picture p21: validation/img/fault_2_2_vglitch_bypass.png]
Voltage-glitch password bypass window


#### Fault 2_3: Voltage Glitching to Memory Dump

`bootloader-glitch` answers a command with an 8-byte ack, sending exactly `ascii_idx` bytes via
`for(i=0; i<ascii_idx; i++) putch(ascii_buffer[i])`. A crowbar glitch on that loop bound makes the target
keep sending past the ack, dumping the adjacent buffer and RAM (including the decrypted `data_buffer`).
Script: `validation/scripts/fault_2_3_memory_dump.py`.

- Glitch: high-power crowbar, width 2000, offset 2480, ext_offset 2122 (inside the send loop,
  trig_count 2159).
- Result: the 8-byte ack became a **601-byte memory dump**: the leftover input buffer plus a block of
  binary RAM. The success marker `767` that this attack scans for is present in the leak (offset 0x2a).
- Success is rare: on the standard board the first success appeared after about 2100 swept attempts, which
  is a single-event sweep position (the ordinal of the one success in an ordered parameter sweep) rather
  than a per-shot hit rate, so treat it as order-of-magnitude only. It is rare because the glitch must land
  on the last loop-bound check (a narrow window) on top of the base glitch rate. The dump length varies with
  the exact glitch (the CW313 produced a 510-byte dump at the same parameters that gave 601 bytes on the
  standard board, and the Right-Angle a 510-byte dump at a different glitch point).

Full hexdump evidence: [`fault_2_3_memory_dump.txt`](validation/evidence/fault_2_3_memory_dump.txt).

#### Clock glitching

In ChipWhisperer's stock configuration the CW312T-SAM4S runs its Cortex-M4 core **directly from the
external HS2 clock**: the SAM4S HAL switches the master clock to MAINCK in bypass mode (`~7.37 MHz`,
prescaler 1) and does not engage the PLLA in the core path. This is visible in
`firmware/mcu/hal/sam4s/sam4s_hal.c` (`osc_enable(OSC_MAINCK_BYPASS)` then
`pmc_switch_mck_to_mainck(SYSCLK_PRES_1)`), and is corroborated by the synchronous 7.363636 MHz capture
clock. A clock glitch on HS2 therefore propagates into the core clock tree (MCK/HCLK) with no PLL to
regenerate it. The matching capture clock is consistent with this bypass configuration but not by itself
proof that no PLL is engaged; the decisive evidence is the HAL source, and that clock glitching in fact
produced faults.

(For reference, on genuinely PLL-clocked systems the PLL strongly attenuates single external-clock
glitches, so a naive single-cycle external glitch is usually ineffective, and faulting instead works by
perturbing the PLL itself, for example by driving it into a transient frequency overshoot through
manipulation of the external reference clock; see Selmke,
Hauschild and Obermaier, "Peak Clock: Fault Injection into PLL-Based Systems via Clock Manipulation,"
ASHES@CCS 2019, Fraunhofer AISEC / ACM, DOI 10.1145/3338508.3359577. That is not the configuration used
here, where the SAM4S core runs on the bare external clock.)

- **Via CW313 direct** (short path, no UFO/Abductor): the clock glitch crashes the SAM4S (crash rate
  rising with glitch width). A single clean password bypass was captured at the crash onset (width 3450,
  offset 2300, ext_offset 142); this was one observed event, so no success rate can be estimated from it.
- **Via UFO + Abductor:** at the same reactive region (width ~3400, offset 2300, ext ~120-140) the glitch
  faults the SAM4S too. The effect scales with `scope.glitch.repeat` (consecutive glitched cycles): the
  crash rate rises with repeat (roughly a few percent at repeat 1 to roughly 40% at repeat 32; single
  sweep), with clean password bypasses at repeat 4, 8 and 16.

A narrower UFO+Abductor sweep earlier missed this exact reactive parameter combination (it swept width
fully but the wrong ext_offset window, or the right ext_offset at the wrong widths), which wrongly
suggested "zero effect" and path attenuation. Testing at the correct parameters shows the Abductor does
fault the SAM4S. These single, unmatched runs cannot establish whether a path effect exists: the
Abductor's clean bypasses appeared only at higher repeat than the one CW313 event, which is suggestive,
but a single uncontrolled CW313 observation cannot confirm it; matched sweeps on both paths would be
needed to decide. Clock glitching this SAM4S was crash-dominated regardless of path, with clean faults
comparatively rare; the practical tip is to use a higher `scope.glitch.repeat` for more frequent clean
faults. Scripts: `validation/scripts/clock_glitch_cw313_bypass.py`,
`validation/scripts/clock_glitch_abductor_repeat.py`.

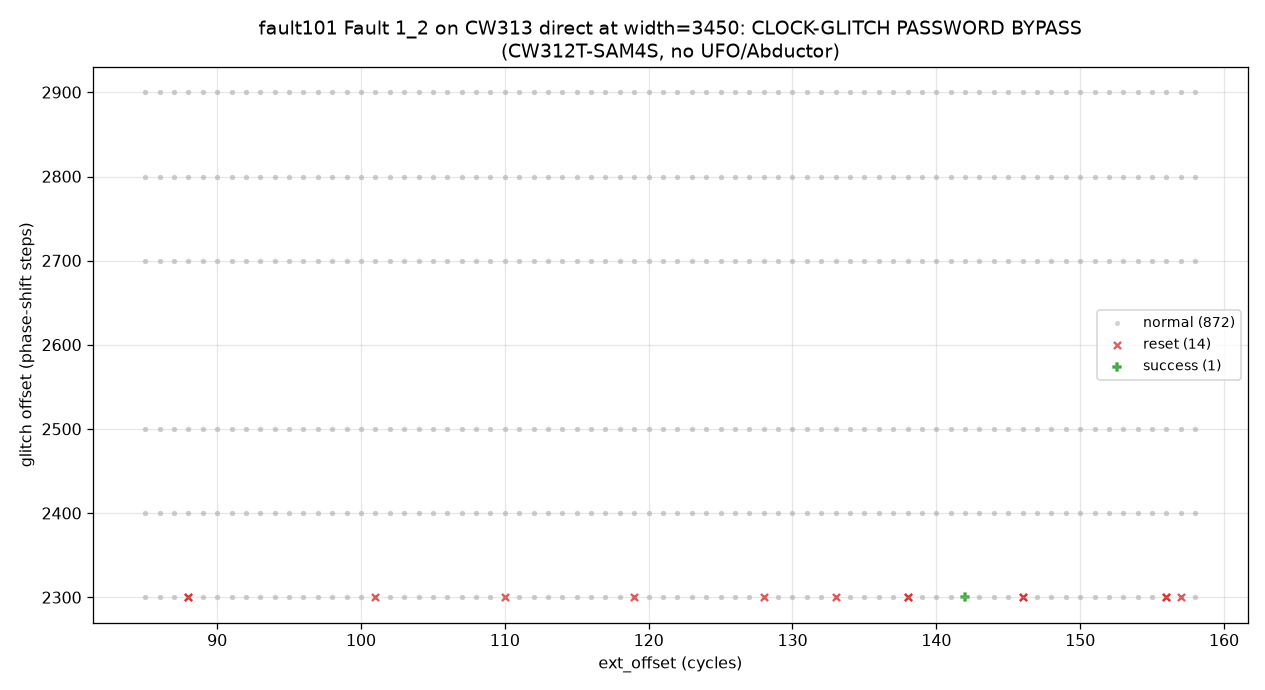
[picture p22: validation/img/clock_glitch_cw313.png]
Clock-glitch password bypass on CW313 direct (green + at width 3450, offset 2300, ext 142)


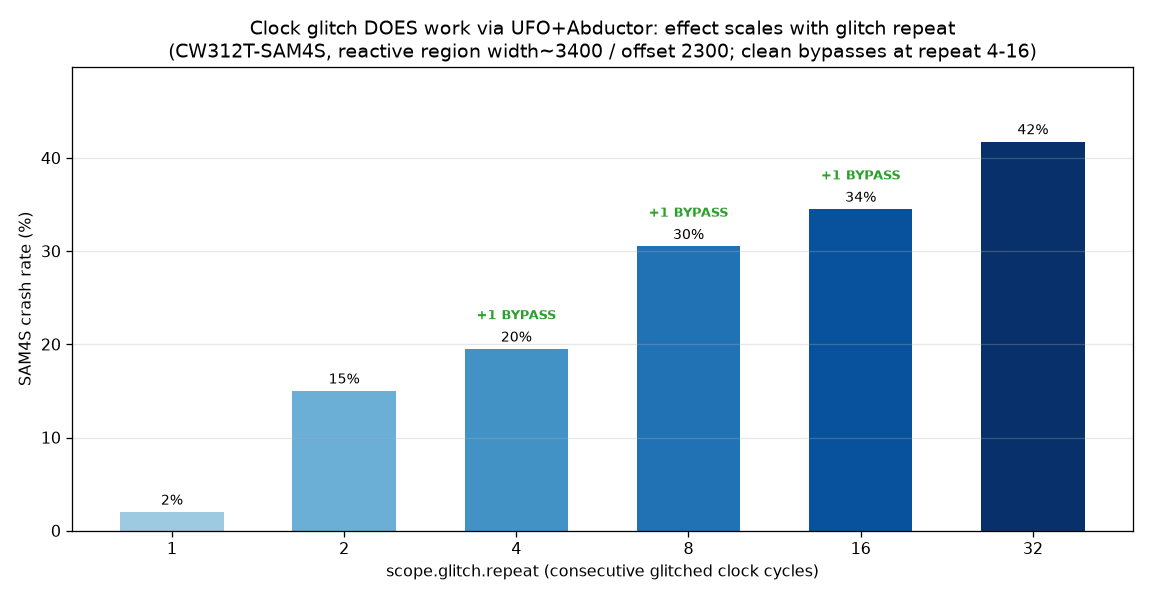
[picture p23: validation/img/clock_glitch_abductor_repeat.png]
Clock glitch works via UFO+Abductor: effect scales with glitch repeat, clean bypasses at repeat 4-16


#### Voltage-glitch reliability: connector and path comparison

This measures peak bypass rate at each configuration's best cell (an apparent optimum over the swept grid,
not verified as global): a fine search for the best cell, then 40 attempts there. A bypass means a wrong
password was accepted. Benchmark: `validation/scripts/vglitch_peakrate.py`.

Clean back-to-back comparison on the same freshly re-assembled UFO + Abductor:

| VOUT tee | Peak bypass rate |
|---|---|
| quality tee (Amphenol 132217) | 31/40 = **78%** |
| cheap tee (ships with the UFO) | 22/40 = **55%** |

Other measurements (different re-assemblies, for context): quality tee 39/40 = 98% on an earlier run;
CW313 direct with 2 dedicated SMAs and no tee, 34/40 = 85%. The quality tee is an **Amphenol 132217**
(SMA jack-plug-jack T, Mouser 523-132217); the cheap tee is the one that ships with the CW308 UFO.

A complementary figure is the batch-averaged bypass rate over a larger 200-shot batch (five 40-shot
batches, `validation/scripts/vglitch_rate_robust.py`) at each path's matched same-day optimum: 49.5% on the
UFO plus Abductor and 40.5% on the CW313 direct. That 9-point gap
is about 1.8 standard errors of the difference (SE of the difference ~5%; z ~ 1.8, two-sided p ~ 0.07),
i.e. not resolvable at 200 shots per path. These are the values in the results table above; being
200-shot averages rather than best-cell peaks, they sit below the 40-shot peak rates.

Conclusions:

- **Within this data, the Abductor path is not measurably worse than a direct CW313 connection.** All
  tested configurations produced frequent bypasses (peak rates 55% to 98%, each a single 40-shot run). The
  UFO plus Abductor path with a good tee (78% to 98%) overlaps the direct CW313 connection (85%); all are
  single 40-shot measurements with substantial run-to-run variance, so no path can be ranked above another.
- **The quality tee may help, but the effect is not established.** On a clean back-to-back run the good tee
  gave 78% vs the cheap tee's 55% (31/40 vs 22/40), but a two-sided Fisher exact test on those counts gives only
  p ~ 0.06 (not significant at the 0.05 level), so a single n=40 pair cannot settle whether the tee helps,
  and the difference lies within the run-to-run variance seen elsewhere. It is far smaller than the first,
  uncontrolled numbers suggested (an apparent 40% vs 98%), which were inflated by a grid-edge underestimate
  on one side and by re-assembly variance.
- **Voltage-glitch rates carry real run-to-run and re-assembly variance** (the good tee measured 78% and
  98% on two different re-assemblies), so single 40-shot measurements cannot resolve a modest tee effect
  with certainty; repeated swap-and-measure runs would be needed to pin it down.

Practical takeaway: in these tests the Abductor carried voltage glitching with either tee. The Amphenol
tee is a reasonable low-cost option, not a demonstrated necessity.

### JTAG/SWD debug (halt and memory readout)

Side channel and fault injection cover the power, clock, serial and crowbar paths. The last signal class
the Abductor has to route is the SAM4S debug port. Using the Husky Plus in MPSSE mode (the FTDI emulation
the Husky exposes) together with OpenOCD, the SAM4S was taken over via SWD: the core was reset and halted at its
reset vector, then the chip ID, SRAM, flash and core registers were read out. This exercises the Abductor's
`JTAG_TMS` and `JTAG_TCK` routing (SWDIO and SWCLK).

The Husky drives SWD in non-DIO mode (`scope.enable_MPSSE(1)`), which puts the debug signals on the main
20-pin SPI/PDI pins: **PDID is SWDIO** and **SCK is SWCLK** (the standard ChipWhisperer mapping for the
non-Husky boards). OpenOCD then connects with `transport select swd` and the `at91sam4sXX` target config.

**Reference: CW313 direct (isolation).** The debug flow was first verified on the CW313 baseboard, with
the SAM4S plugged in directly and no Abductor, to confirm the target and the toolchain. On the CW313 the
bridge is made with the on-board **JP3** jumpers (`PDID`/`JTAG_TMS`, `SCK`/`JTAG_TCK`, `nRST`/`JTAG_nRST`),
so no external wiring is needed.

**Through the UFO + Abductor.** The same session was then run through the adapter, the chain being Husky
Plus, CW308 UFO, Abductor, CW312T-SAM4S. The CW308 UFO has no JP3, so the bridge is four wires from the
target-IO header to the UFO JTAG header `J8`:

| Wire | From | To (J8) | Role |
|---|---|---|---|
| 1 | `SCK` | `J_TCK` | SWCLK |
| 2 | `PDID/CS` | `J_TMS` | SWDIO |
| 3 | `VREF` | `J_UREF` | JTAG_VREF for the pull-ups |
| 4 | `nRST` | `J_TRST` | CW reset line jumpered to the JTAG `J_TRST` pin on the UFO JTAG header |

The `VREF` to `J_UREF` wire is not optional. On the CW308 UFO the `JTAG_VREF` net is not driven by the
board (it only feeds the 100k pull-ups on the JTAG lines), so without it the SWDIO idle level floats and
the SWD handshake fails with "cannot read IDR". The CW313 already powers that reference, which is why it
needs no VREF wire. From `J8` the debug lines reach the CPU via the UFO target socket, the Abductor, and
the CW312 edge.

The debug readout through the Abductor is below (the path-invariant part is the fixed silicon and debug-port
identifiers; the vector table and the pc and sp are firmware-dependent, and differ from the CW313 run only
because a different build happened to be loaded there):

| Read over SWD | Value | Meaning |
|---|---|---|
| SWD DPIDR | `0x2ba01477` | ARM CoreSight SW-DP (DPv1) alive, a common DPIDR across ARM Cortex-M3/M4 parts; it identifies the debug port, not the core |
| Core | `Cortex-M4 r0p1` | SAM4S core identified from CPUID |
| State | `halted due to debug-request` | core halted by the debugger immediately out of reset, so it stopped at the reset vector |
| CHIPID_CIDR @0x400E0740 | `0x288b07e1` | chip ID read from silicon (decodes to ATSAM4S2A: Cortex-M4, 128 KB flash, 64 KB SRAM) |
| Flash @0x00400000 | SP `0x200011a8`, reset vector word `0x0040061d` | firmware vector table (the reset entry has bit 0 set for Thumb state, so it points at handler address `0x0040061c`) |
| Registers | pc `0x0040061c`, sp `0x200011a8` | pc matches the reset handler address (the reset vector word `0x0040061d` with its Thumb bit cleared) and sp matches the vector-table MSP, as expected for a reset-halt |

The fixed identifiers read through the Abductor (DPIDR, the CPUID core revision, and the CHIPID) match the
CW313 reference bit for bit, and the halt, flash and register reads behave identically, which is consistent
with the Abductor's JTAG/SWD routing being correct: SWDIO (the TMS-position pin) and SWCLK (the TCK-position pin) carry the
SWD transaction end to end from the CW312 edge to the CW308 socket. The DPIDR identifies an ARM CoreSight
debug port, not the core type; the Cortex-M4 identity comes from the CPUID read (r0p1) and the CHIPID.
This is a full debug takeover (halt, chip ID, SRAM and flash read, core registers) over the adapter. Full
evidence: [`swd_cw313_dump.txt`](validation/evidence/swd_cw313_dump.txt) and [`swd_abductor_dump.txt`](validation/evidence/swd_abductor_dump.txt).

**Full JTAG (TDI and TDO).** SWD uses only two lines, SWDIO and SWCLK, carried on the TMS-position and
TCK-position pins; it does not use the TDI/TDO pins. To also exercise the two remaining debug data lines,
`JTAG_TDI` and `JTAG_TDO`, the session was repeated in full JTAG mode (`transport select jtag`) with two
more wires added on the UFO, `MOSI` to `J_TDI` and `MISO` to `J_TDO` (six wires total). OpenOCD read the
JTAG TAP by scanning the chain, which only completes if the TDI to TDO path through the chip is intact:

| Read over JTAG | Value | Meaning |
|---|---|---|
| TAP IDCODE | `0x4ba00477` (matches expected) | ARM CoreSight JTAG-DP (mfg 0x23b = ARM, part 0xba00, ver 0x4), captured in Capture-DR and read out on TDO by scanning the chain |
| Core | `Cortex-M4 r0p1` | same core, identified from CPUID over JTAG |
| CHIPID_CIDR @0x400E0740 | `0x288b07e1` | chip ID, read over JTAG |

The halt, flash, SRAM and register reads over JTAG shift their commands into the chip through TDI and
return data on TDO, so the JTAG session exercises the Abductor's `JTAG_TDI` (MOSI) and `JTAG_TDO` (MISO)
routing on top of the SWD result (the 32-bit IDCODE itself is captured into the shift register in parallel
and read back on TDO, so it alone confirms TDO, while the reads that follow are what additionally exercise
TDI). The TAP IDCODE
`0x4ba00477` differs from the SWD DP IDR `0x2ba01477`, as expected: they are the identification registers
of the two personalities (JTAG-DP and SW-DP) of the same CoreSight SWJ-DP debug port (the SW-DP DPIDR
carries a DP-version field in bits [15:12] that the
IEEE-1149.1 JTAG IDCODE does not, and encodes PARTNO in 8 bits vs the JTAG format's 16). As noted above,
both are debug-port IDs, not core IDs. So the CW312T-SAM4S is not SWD-only, and every debug line the
Abductor carries is exercised: the data lines TDI and TDO, the control lines TMS and TCK, plus reset
(nRST) and reference (VREF). Evidence: [`jtag_abductor_dump.txt`](validation/evidence/jtag_abductor_dump.txt).

Tooling: OpenOCD 0.12.0, Husky Plus in MPSSE mode (USB PID stays `0xace6`), stock ChipWhisperer interface
config `openocd/cw_openocd.cfg`. Scripts: `validation/scripts/swd_debug.sh`, `validation/scripts/jtag_debug.sh`.

### Signal coverage and integrity

Beyond the main demos, the remaining Abductor-routed signals were checked so each pin the adapter carries
was functionally exercised, continuity-verified, or documented as not applicable (see the coverage matrix),
and the signal path was characterized with two standard leakage-assessment metrics (SNR and TVLA). The functional
tests run small firmwares on the SAM4S (sources under `validation/scripts/firmware/`, runner
`validation/scripts/signal_test.py`); the pin map is taken from the CW312T-SAM4S schematic.

#### Signal integrity (SNR and TVLA)

Two standard leakage-assessment metrics (SNR and TVLA) quantify how cleanly the Abductor's measurement
path captures the AES leakage (`validation/scripts/signal_integrity.py`, 3000-sample window on
`simpleserial-aes`):

- **SNR**: `chipwhisperer.analyzer`'s `calculate_snr` with the S-box (SubBytes) output Hamming-weight model
  (byte 0, 1500 random-plaintext traces) gives a peak **linear SNR of 14.1 (11.5 dB)** at the leak sample,
  i.e. a signal variance about 14 times the noise variance. (Note: in ChipWhisperer's source,
  `calculate_snr(db=True)` returns `20*np.log(snr)`, and `numpy.log` is the natural logarithm, so it
  reports `20*ln(snr)`, which is not standard dB; the dB values quoted here are the proper `10*log10` of
  the linear SNR. See `software/chipwhisperer/analyzer/attacks/snr.py`.)
- **TVLA**: a non-specific fixed-vs-random Welch t-test (the leakage-detection methodology of Goodwill, Jun,
  Jaffe and Rohatgi, 2011, later branded TVLA; ~1500 fixed and ~1500 random traces, 3000 total, split
  fixed-vs-random by a per-trace coin flip) reaches **max |t| = 60.7**, far above the conventional 4.5
  detection threshold. The measurement chain passes the data-dependent leakage through with a large, easily
  detectable signal.

Both metrics were then repeated with the SAM4S in the CW313 baseboard directly (no UFO, no Abductor) as an
A/B reference at the same target and trace count, so that only the signal path differs and any gap points to
the path rather than the target (a raw t-value also grows with the trace count, so it is used here only as a
matched-count relative measure, not as an absolute score):

| Path | SNR peak (linear / dB) | TVLA max \|t\| |
|---|---|---|
| UFO + Abductor | 14.1 / 11.5 dB | 60.7 |
| CW313 direct (reference) | 16.7 / 12.2 dB | 60.7 |

The TVLA max |t| came out at 60.7 on both paths in these single runs; an exact match at three significant
figures across two independent trace sets is coincidental and should not be read as reproducible to that
precision. The point is only that both sit far above the 4.5 threshold with no order-of-magnitude
difference. The SNR differs by about 0.7 dB (11.5 vs 12.2 dB; 14.1 vs 16.7 linear), the direct path being
slightly higher. With only one SNR estimate per path there is no sampling distribution, so this small a
difference cannot be tested at all: the adapter's point estimate is slightly lower and is neither confirmed
nor excluded as a real effect. Confirming the absence (or presence) of a small systematic effect would need
matched repeated sweeps on both paths.

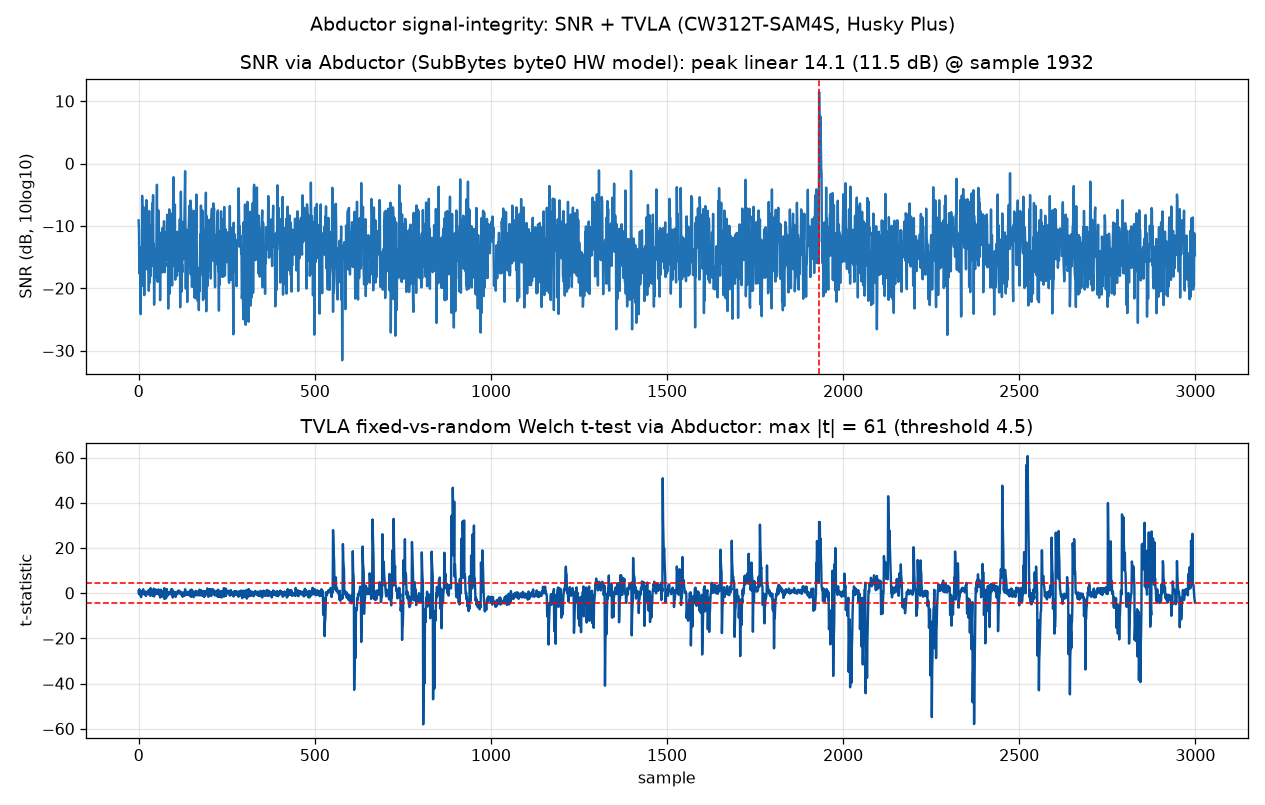
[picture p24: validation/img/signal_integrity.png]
Signal integrity, UFO + Abductor


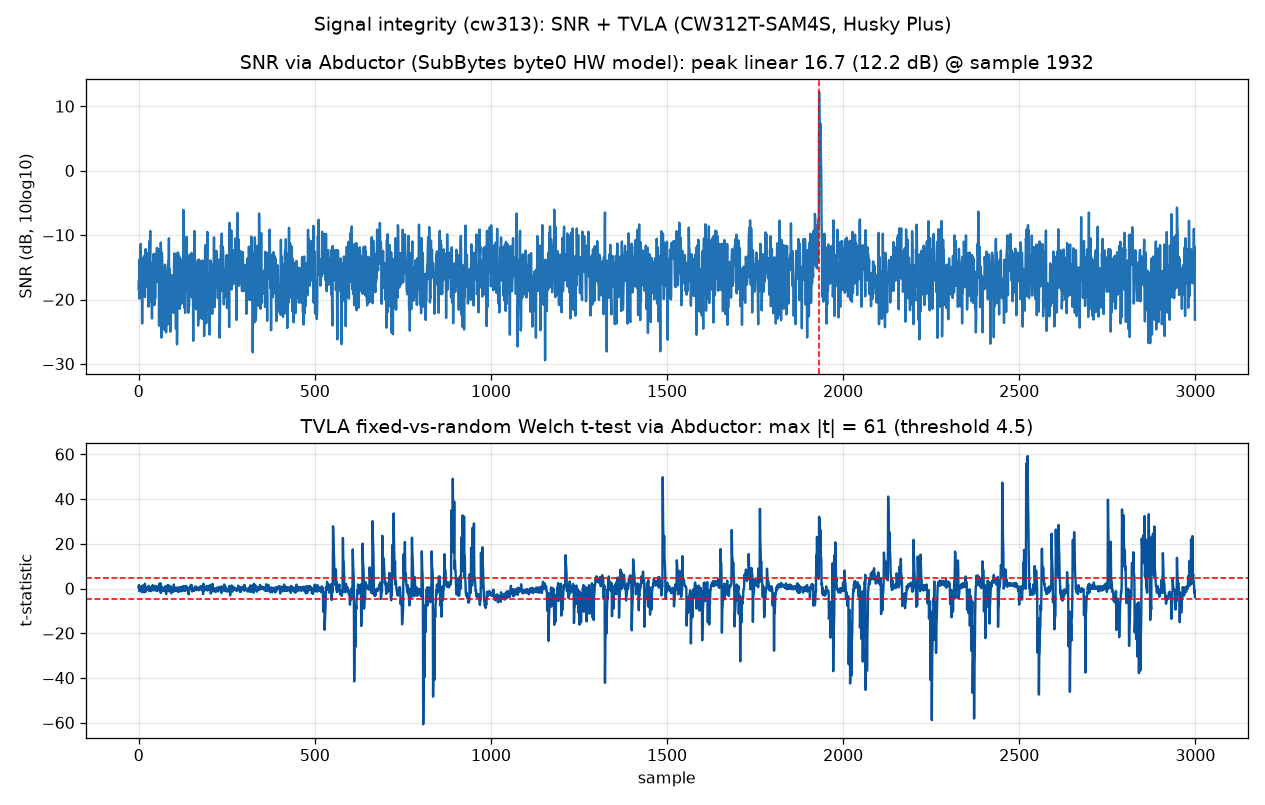
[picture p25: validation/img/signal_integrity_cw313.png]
Signal integrity, CW313 direct reference


**Possible future work.** The SNR and TVLA figures above are derived from the ChipWhisperer capture path
itself, not from a direct bench measurement of the board. In the future I may probe the Abductor more
directly with my MHO98 and an LD-ASP-2.7 single-ended active probe, to take additional signal-integrity
measurements on both the standard and the Right-Angle Abductor. Any such results would be added here.

#### LED1 / LED2 / LED3 (PA16 / PA15 / PA14)

`led-blink.c` drives the three target LED lines in sequence. All three CW308 LEDs light one after the
other, which confirms the Abductor routes LED1, LED2 and LED3 from the SAM4S to the UFO.

#### GPIO3 (PA8)

`abductor-sigtest.c` drives GPIO3 as a slow square wave. Reading `scope.io.tio_states` on the CW, TIO3
follows it (observed at both 0 and 1), which confirms GPIO3 is routed and that the on-board `SJ1` jumper is
in its GPIO3 position. The same firmware also outputs PCK0 (MAINCK/8) on PA6 = CLK_FROM_SAM (the target
clock-out); the Husky frequency counter does not read the CW308 clock-out path without extra clock-routing
setup, so CLKOUT is confirmed by continuity instead.

#### FILT_LP (low-power crowbar)

The HP crowbar was exercised by the voltage-glitch password bypass above. `fault_2_2_vglitch_lp.py`
exercises the other crowbar transistor with `scope.vglitch_setup('lp')` and sweeps `scope.glitch.repeat`.
The fault is cleanly controlled by the repeat count: no resets were observed at repeat 1 (0 of 18
attempts, a small sample, so a low residual rate is not excluded), and at repeat 2 and above the low-power
crowbar crashed the SAM4S on every attempt in this sweep. The sharp repeat-dependent threshold indicates
the FILT_LP crowbar path reaches the target through the VOUT node, and that the resets track the glitch
parameter rather than occurring at random.

#### Coverage matrix

| Abductor signal | SAM4S pin | Validated by | Status |
|---|---|---|---|
| VCC (1.2 core, 3.3 IO), VREF, SHUNTL/H | power net | SCA / power capture | ✅ |
| CLKIN (HS2) | XIN / PB9 | SCA + clock glitch | ✅ |
| GPIO1_TX / GPIO2_RX | PA10 / PA9 | serial (password bypass) | ✅ |
| GPIO4 / trigger | PA7 | capture trigger | ✅ |
| nRST, PDIC (ERASE) | RST / PB12 | SAM-BA programming | ✅ |
| FILT_HP / VOUT (crowbar HP) | power net | voltage glitch | ✅ |
| JTAG TMS / TCK / TDI / TDO | PB6 / PB7 / PB4 / PB5 | SWD + full JTAG | ✅ |
| JTAG_VREF / JTAG_nRST | debug net | SWD / JTAG (VREF, nRST wires) | ✅ |
| LED1 / LED2 / LED3 | PA16 / PA15 / PA14 | led-blink firmware (visual) | ✅ |
| GPIO3 | PA8 | sigtest firmware (TIO3 read-back) | ✅ |
| CLKOUT (CLK_FROM_SAM) | PA6 (PCK0) | continuity (CW312 edge A29 to UFO CLKOUT) | ✅ |
| FILT_LP (crowbar LP) | power net | low-power crowbar glitch (repeat 1 clean, repeat >=2 crash) | ✅ |
| VCC1.8 / 2.5 / 5.0 / VADJ | power net | continuity (unused by SAM4S) | ✅ |
| HDR1-10, JTAG_TRST | passthrough | continuity | ✅ |
| TRACECLK, TRACED0-3 | not wired to SAM4S (no ETM) | not applicable, see note | N/A |

The SAM4S does not use several routed rails and passthrough pins (the extra VCC rails, HDR1-10, the
differential clock, CLKOUT), so those were confirmed with a continuity check from the CW312 edge to the
CW308 breakout rather than a functional demo. Each checked net was electrically continuous, so the
passthrough routing is connected as intended.

**Parallel trace (TRACECLK, TRACED0-3).** The parallel ETM trace pins are not applicable on this setup, on
both ends. On the target side, the ATSAM4S2 has no ETM and no parallel trace port, so it cannot emit parallel trace (NewAE's own
"Husky TraceWhisperer Exploration" demo states the SAM4S cannot be used for that reason), and the
CW312T-SAM4S schematic shows `TRACECLK` and `TRACED0-3` are not wired to the microcontroller at all (they
are unconnected CW312 edge pins). On the carrier side, the CW308 UFO schematic (a 2016 design) does not
break out trace pins either. So there is no trace path to exercise or even to continuity-check on either
side; this is a target and carrier limitation, not an Abductor issue. The SAM4S's single-wire trace output
(SWO) shares the `TDO/TRACESWO` pin, which is already exercised as `JTAG_TDO` in the full JTAG test above.

## Second target: CW312T-iCE40UP FPGA

To confirm the Abductor works with a completely different class of target, a **CW312T-iCE40UP** (a Lattice
iCE40 UltraPlus iCE40UP5K FPGA, ~5280 LUTs, in a 30-ball WLCSP) was placed in the Abductor in place of the
SAM4S. Unlike the MCU, this target is a hardware AES core in FPGA fabric: it is configured with a bitstream
over SPI, talks over the SS2 wrapper, and leaks on the last AES round. All results below are through the
Abductor, and each was re-run with the iCE40 moved into the CW313 baseboard directly as a reference; the
two setups agree on every attack outcome, with only minor differences in the raw leakage metrics.

- **Bitstream config:** the `iCE40UP5K_SS2` AES bitstream loads and the FPGA configures cleanly, so the
  Abductor routes the FPGA's SPI configuration path (SCK/MOSI/MISO/CS) correctly.
- **AES correctness:** a known-answer test passes (`AES(0, 0) = 66e94bd4ef8a2c3b884cfa59ca342b2e`), so the
  serial (SS2) and clock reach the FPGA and the core runs.
- **CPA key recovery:** with the last-round Hamming-distance model (`cwa.leakage_models.last_round_state_diff`,
  the Hamming distance between the round-9 and round-10 state-register values, valid for this round-based
  single-round-per-cycle core), CPA over **5000 traces** recovers the round-10 key, and the inverse key
  schedule derives the full master key, **16/16 bytes correct** (`2b7e151628aed2a6abf7158809cf4f3c`). This
  needs thousands of traces rather than the ~30 for the SAM4S software AES: in the parallel FPGA core a full
  AES round completes in one clock cycle and all 16 S-boxes switch simultaneously, so the SNR of any single
  targeted byte is far lower (algorithmic noise from the other 15 bytes) than in the byte-serial software
  AES, whose S-box leakage is spread over many cycles. The hardware AES still leaks strongly overall; see
  the TVLA below.
- **Leakage metrics (through the Abductor):** two standard metrics quantify the measurement quality the
  Abductor delivers for this hardware target. **CPA convergence** (same last-round HD model) recovers the
  full 16-byte key at **3000 traces** in this run (8/16 bytes already by 700 traces, 15/16 by 2000), below
  the safe 5000 used above. A non-specific **TVLA** (fixed-vs-random Welch t-test, ~2000 + 2000 traces)
  gives a **max |t| of 85** against the 4.5 detection threshold, so the hardware AES produces a strong
  first-order leakage signal across the Abductor's power path. Plots: `validation/img/ice40_cpa_convergence.png`
  and `validation/img/ice40_tvla.png`; script `validation/scripts/ice40_sca_metrics.py`. *CW313 reference:*
  comparable convergence (full key at **3000 traces**) and a comparable TVLA (**max |t| = 89.3** vs 85.0), so
  the measurement path behaved the same on both setups (`validation/img/cw313/ice40_cpa_convergence.png`,
  `validation/img/cw313/ice40_tvla.png`).
- **Fault injection (full DFA key recovery):** a clock glitch on HS2 (the FPGA's clock) faults the AES core,
  and the fault is exploitable end to end. The attack follows the official ChipWhisperer DFA lab
  (`fault201 Lab 1_3B - DFA Attack on AES`) and uses the same cracker, **`phoenixAES`** (Philippe Teuwen's
  tool, in the JeanGrey repository of the SideChannelMarvels project). Two fault models were used, both first
  validated in software against this FPGA's own ciphertext (`validation/scripts/dfa_selftest.py` reproduces
  the exact bench value `AES(2b7e..,00..0f) = 50fe67cc996d32b6da0937e99bafec60` and the definitive
  known-answer `AES(0,0) = 66e94bd4...`, then recovers the key from simulated faults, so the cracker and the
  fault model are validated in software before any hardware time):
  - *Round-9 (Piret & Quisquater) fault:* a single-byte fault just before the last MixColumns gives a 4-byte
    diagonal ciphertext difference (e.g. bytes 0/7/10/13). This works, but the FPGA runs a **parallel** AES,
    so a fixed plaintext faults only one **data-dependent** diagonal; recovering all four diagonals this way
    was impractical in this campaign (across the limited plaintexts tried, one diagonal did not appear). More
    plaintexts might surface it, so this is not established as impractical in general.
  - *Round-8 fault (the model that succeeded):* a single-byte fault one round earlier fully diffuses, and
    `phoenixAES.convert_r8faults_bytes` expands one such near-fully-corrupted output into a round-9 fault on
    **all four diagonals at once**, so a few clean round-8 faults from just one or two plaintexts are enough.
    In practice the known-answer plaintext yielded 12/16 round-10-key bytes (diagonals 0,1,2) and a second
    plaintext supplied the last diagonal.
  - **Result:** the recovered round-10 key is `d014f9a8c9ee2589e13f0cc8b6630ca6`; inverting the AES key
    schedule (`aes_funcs.key_schedule_rounds(r10, 10, 0)`) gives the master key **`2b7e151628aed2a6abf7158809cf4f3c`,
    16/16 bytes correct**. So the Abductor's clock-glitch path carried a complete differential fault attack on
    the FPGA fabric. Scripts: `validation/scripts/dfa_selftest.py` (software proof) and
    `validation/scripts/ice40_dfa_phoenix.py` (hardware attack); evidence in [`ice40_dfa_abductor.txt`](validation/evidence/ice40_dfa_abductor.txt).
    *CW313 reference:* the same attack on the CW313-direct setup also recovers the full key (16/16, round-8
    route); evidence in [`ice40_dfa_cw313.txt`](validation/evidence/ice40_dfa_cw313.txt).

So for this iCE40 target the Abductor carried everything it needed (SPI config, serial, clock, a clean
enough power measurement for a hardware-AES CPA, and a clock-glitch path strong enough to fully key-recover
the fabric by DFA), the same capability set it provides for the MCU. Script:
`validation/scripts/ice40_hw_aes_cpa.py`.

Note: the SS2 serial only worked once the SAM4S SWD/JTAG jumper wires were removed from the UFO. Those
wires tie `nRST` / `VREF` / SPI to the `J8` JTAG header, which interferes with the FPGA's operation; they
are not needed for any iCE40 test.

## Third target: CW312T-K82F hardware crypto accelerator

To stretch the Abductor to a third, very different class of target, a **CW312T-K82F** (NXP Kinetis
MK82FN256, a Cortex-M4F) was placed in the Abductor in place of the SAM4S. The K82 carries two cryptographic
blocks: the **mmCAU** (Memory-Mapped Cryptographic Acceleration Unit) and the separate **LTC** (LP Trusted
Crypto) co-processor. The firmware tested here attacks the **mmCAU** hardware AES (`CRYPTO_OPTIONS=MMCAU`);
the DPA-mask study further below concerns the LTC engine, a different block. The distinction matters: the
mmCAU is a throughput accelerator for software crypto, with no DPA or side-channel countermeasure of its own
(the K82's hardware DPA countermeasure lives in the LTC), so any non-recovery reported below reflects
measurement effort and low per-byte SNR, not a designed-in resistance. Unlike the SAM4S's plain software AES
and the iCE40's full FPGA AES core, this target runs AES with dedicated on-chip crypto acceleration. All
results are through the Abductor unless a CW313 comparison is given.

- **Bring-up:** the K82F does have an on-chip ROM serial bootloader (KBOOT, entered by pulling PTA4 low, over
  UART/USB), but NewAE recommends flashing this target over **SWD/JTAG**, which is the path used here. It was
  flashed through the Abductor using the Husky's MPSSE mode and OpenOCD (`kx.cfg`), the same debug path the
  SAM4S SWD used (`SWCLK/SWDIO/reset` wired on the UFO `J8`). A known-answer test then passes
  (`AES(2b7e.., 00..0f) = 50fe67cc996d32b6da0937e99bafec60`), so the SWD flash, the 7.37 MHz HS2 clock, the
  LPUART serial, the trigger and the mmCAU-accelerated AES all reach the K82F through the Abductor. Scripts:
  `validation/scripts/k82f_flash.sh`, `validation/scripts/k82f_bringup.py`; firmware in
  `validation/scripts/firmware/k82f/` (built with `PLATFORM=CW308_K82F CRYPTO_TARGET=HWAES
  CRYPTO_OPTIONS=MMCAU SS_VER=SS_VER_2_1`).
- **Leakage present (TVLA):** a non-specific fixed-vs-random Welch t-test on the mmCAU hardware AES gives
  **max |t| = 100.6** (8k traces), far above the 4.5 threshold, so the Abductor's power path clearly captures
  the accelerator's data-dependent activity. Script: `validation/scripts/k82f_tvla.py`.
- **CPA effort:** despite that strong total leakage, the mmCAU hardware AES was **not broken by standard
  first-order CPA** here (up to 50k traces, blind and profiled). With the known key as an oracle, only
  **byte 0 leaks clearly** (`|rho| = 0.104`), bytes 8 and 14 leak weakly (`~0.04-0.06`), and the other twelve
  bytes sit at the noise floor (`~0.02`). A blind full-window CPA returns the correct guess for ~4/16 bytes;
  three of those coincide with the bytes that leak against the known-key oracle (0, 8, 14) and the rest are
  consistent with full-window ghost peaks (random guessing would place only about 0.06 bytes correct out of 16, that is 16 times 1/256, so this is a few
  genuinely leaky bytes plus false positives, not chance). A **rigorous profiled attack with disjoint
  profiling/attack sets** recovers only ~1/16. So the full key was not recovered by any first-order
  correlation attack tried here under this measurement setup; a stronger attacker, a better model, or a higher
  trace budget is not ruled out. (Methodological note: a *self-profiled* matched-filter or POI attack reports
  a false 16/16 because the profile is built from, and then evaluated on, the same traces, with no disjoint
  profiling/attack split, so it overfits that set's noise; the disjoint-set control is what tells the truth.
  Scripts: `validation/scripts/k82f_cpa.py`, `validation/scripts/k82f_leakcheck.py`,
  `validation/scripts/k82f_models.py`, `validation/scripts/k82f_mf_rigor.py`.)
- **Control: target or adapter?** To test whether this non-recovery is a property of the K82F itself and not
  the Abductor degrading the signal, the identical 50k-trace experiment was repeated with the K82F in the
  **CW313** baseboard directly. The two setups match on the outcome: byte-0 `|rho|` **0.104 (Abductor) vs
  0.095 (CW313)**, the same handful of leaky bytes, and neither is broken (full key unrecovered). The CW313
  capture was in fact slightly **noisier** (median 6.1e-3 vs 4.0e-3) with a lower TVLA (65.8 vs 100.6, both at 8k traces), so in
  this session the Abductor did not degrade the measurement relative to the direct path (it was, if anything,
  the cleaner of the two). This points to the non-recovery being a property of the hardware target rather than
  the Abductor, since it persists on the direct CW313 path. Script: `validation/scripts/k82f_compare.py`.
- **DPA countermeasure (inconclusive):** the LTC engine has a hardware DPA mask (`LTC_SetDpaMaskSeed`). The
  mask is seeded at power-on reset; NXP recommends reseeding it every 50000 blocks, but reseeding is
  software-driven, not automatic. Three builds were compared on the same silicon: mask forced constant (off),
  a mask reseeded per NXP's 50000-block recommendation, and a mask reseeded on every encryption. All three
  showed the same |rho| ~ 0.03, with no difference this single-run comparison could resolve (no significance
  test was run), so a first-order difference could not be shown: the measured leakage is dominated by unmasked
  plaintext/ciphertext I/O, and isolating the masked interior would need a middle-round or higher-order attack,
  out of scope here. Scripts: `validation/scripts/k82f_mask_study.py`, `validation/scripts/k82f_mask_variance.py`.

**Three-target picture (power side channel, same Abductor):** software AES on the SAM4S falls in ~30 traces;
the iCE40 FPGA AES fell at roughly 3000 traces in this run (5000 used as a safe margin); the K82F mmCAU
hardware AES was **not broken** by the first-order CPA tried here (up to 50k traces). The Abductor covers a
wide range of attack difficulty across these three targets, and in each case the CW313 control indicates the
Abductor was not the limiting factor.

## Second hardware variant: the Right-Angle Abductor

Everything above uses the standard Abductor. There is a second hardware variant of the same board, the
**Right-Angle Abductor** (abbreviated RA), which mounts the CW312 edge with a right-angle connector. As a
result its PCB traces run a little longer and are routed differently, which could in principle add series
inductance and loop area on the crowbar/VOUT and shunt paths, or slightly reduce measurement bandwidth,
rather than simply attenuate a signal. To check that, **all three targets were re-run through the Right-Angle
board** with the same Husky Plus and CW308 UFO, one test at a time, reconnecting the Husky USB between every
test. Any test that failed on the first attempt was re-run after a fixed recovery step (a USB reconnect);
both the initial failure and the retry outcome are reported. The results populate the **Abductor RA** column
of the results table above. In summary, the Right-Angle Abductor produced results consistent with the
standard Abductor in every test; the small differences observed are of the size expected from run-to-run
variation.

### SAM4S (full suite)

- **Signal integrity is comparable (the key measurement).** The SNR peak is **14.0 (11.5 dB)** versus the
  standard board's 14.1, and the non-specific fixed-vs-random TVLA reaches **max |t| = 59.5** versus 60.7.
  Both differ from the standard board by less than the scatter seen between other single runs, so the longer
  right-angle traces produced no attenuation of the side-channel signal that this run could resolve
  (`validation/img/signal_integrity_ra.png`).
- **Side channel recovers the full key as on the standard board, with comparable margins.** CPA reaches rank 0
  (full 16-byte key) at the same **30 traces**; single-bit DPA recovers all 16 bytes; the Lab 2_1B password SPA
  recovers `h0px3` with a 23x to 25x per-character margin; the Lab 2_1A instruction costs are the same to the
  sample (492 / 992 / 2132 / 2276 ADC samples, min equals max), as expected for deterministic timing; and the
  Lab 3_1 Hamming-weight leak sits at the same sample 528 with a comparable ~27x leak-to-noise ratio.
- **Fault injection works through the right-angle crowbar.** The voltage-glitch password bypass lands at the
  **same optimum window** (`ext_offset 129`, widths 1960 to 2200, offsets 2430 to 2500); a 40-shot peak-rate
  measurement at the optimum gives **36/40 bypasses (90%, 95% CI roughly 76 to 97%)**, overlapping the standard
  board's good-tee range; the low-power FILT_LP crowbar shows the same sharp threshold (no crashes at repeat 1,
  crashes in every attempt at repeat >= 2 over the shots run; a small sample, as on the standard board); the
  clock glitch faults the SAM4S with the crash rate scaling from ~2% at repeat 1 to ~40% at repeat 32 (clean
  password bypasses included); and the Fault 2_3 memory-dump attack **leaked a 510-byte dump containing the
  decrypted secret** ("Don't forget to buy milk!") through the right-angle crowbar ([`fault_2_3_memory_dump_ra.txt`](validation/evidence/fault_2_3_memory_dump_ra.txt)).
- **Debug reads match the reference values.** Over SWD the DP IDR is `0x2ba01477` and the chip ID `0x288b07e1`;
  the full JTAG scan reads the TAP IDCODE `0x4ba00477` (exercising TDI to TDO), halts the core and reads flash
  and registers. The ID and IDCODE reads match byte-for-byte, and the halt/flash/register sequence behaves as
  on the standard board and the CW313 ([`swd_abductor_ra_dump.txt`](validation/evidence/swd_abductor_ra_dump.txt), [`jtag_abductor_ra_dump.txt`](validation/evidence/jtag_abductor_ra_dump.txt)). GPIO3 toggles and the three
  target LEDs blink in sequence, so the IO routing is intact too.

Two caveats from this run. First, one test (Lab 3_1) initially failed to program because the SAM4S did not
drop into its SAM-BA bootloader (the programmer read a garbage ChipID, the known intermittent SAM-BA handshake
issue; see Notes and troubleshooting, where it is also noted to occur on the standard board and the CW313, so
it is unlikely to be Right-Angle-specific); a Husky USB reconnect cleared it and the test passed on the retry.
Second, the Fault 2_3 memory dump landed at a different glitch point than the standard board (`(1900, 2200,
ext 88)` instead of `(2000, 2480, ext 2122)`); for a rare probabilistic fault (its single Right-Angle
success came much later in the sweep than the standard board's) this is consistent with there being
multiple valid glitch points, and the result that matters (a real dump of the secret through
the crowbar) is the same.

**SAM4S conclusion:** the Right-Angle Abductor passed the same SAM4S tests as the standard board. Signal
integrity, side-channel key recovery, voltage and clock fault injection, and SWD/JTAG debug all reproduced,
with any effect of the right-angle connector and its longer traces staying within the run-to-run scatter seen
elsewhere in this SAM4S testing. Scripts are the same as for the standard board with an `ra` label argument
(figures under `validation/img/ra/`); evidence in `validation/img/ra/`,
[`fault_2_3_memory_dump_ra.txt`](validation/evidence/fault_2_3_memory_dump_ra.txt),
[`swd_abductor_ra_dump.txt`](validation/evidence/swd_abductor_ra_dump.txt) and [`jtag_abductor_ra_dump.txt`](validation/evidence/jtag_abductor_ra_dump.txt).

### The other two targets on the Right-Angle: iCE40 FPGA and K82F

The FPGA and the hardware-accelerator targets were then moved into the Right-Angle board as well, so all
three target classes are covered on the variant. Both reproduced their standard-Abductor behavior.

- **iCE40UP5K FPGA.** The bitstream configures and the known-answer test passes (`AES(0,0) = 66e94bd4...`), so
  the SPI config, serial and clock all reach the FPGA through the right-angle board. A hardware-AES **CPA
  recovers the full 16-byte key** (last-round HD model, 16/16), the CPA convergence reaches the full key at
  **3000 traces** and a non-specific **TVLA gives max |t| = 85.8** (versus 85.0 on the standard board), and a
  full **DFA with `phoenixAES` recovers the key 16/16** through a clock glitch on the FPGA clock ([`ice40_dfa_ra.txt`](validation/evidence/ice40_dfa_ra.txt),
  figures under `validation/img/ra/`). One note: the first CPA-convergence run needed 5000 traces for the last
  (weakest) key byte; a repeat then reached the full key at 3000, like the standard board. This is most likely
  run-to-run variation on the weakest byte of a parallel hardware AES, though one repeat cannot rule out a
  Right-Angle effect.
- **K82F hardware crypto accelerator.** It flashes over SWD through the right-angle board (Kinetis MK82FN256
  detected, verified OK) and the known-answer test passes (`AES(2b7e.., 00..0f) = 50fe67cc...`). The TVLA is
  strong (**max |t| = 96.0** at 8k traces, versus 100.6 standard), and the mmCAU accelerator was **not broken by first-order
  CPA, to the same extent as on the standard board**. Capturing 30k traces on the Right-Angle and running the
  same rigorous analysis against the standard-Abductor and CW313 caches (all capped to 30k for a fair
  comparison) gives byte-0 `|rho|` **0.104 (Right-Angle) vs 0.104 (standard Abductor) vs 0.091 (CW313; cf.
  0.095 at the full 50k)**, the full key not recovered by first-order CPA in any of the three within 30k traces
  (rigorous disjoint-set 0/16), and a Right-Angle trace-noise floor of **~4.0e-3, comparable to the standard
  board's ~4.0e-3** (the exact 4.01 vs 4.02 agreement is coincidental) and cleaner than the CW313's 6.11e-3. So
  the non-recovery is the target's, and the right-angle board added no distortion this comparison could
  measure, at a comparable noise floor. Script: `validation/scripts/k82f_ra_compare.py`.

**Overall conclusion.** The Right-Angle Abductor reproduced the key outcomes of the standard board across all
three target classes: the SAM4S software AES (full SCA, fault and debug suite), the iCE40 FPGA hardware AES
(CPA, TVLA and a full DFA), and the K82F mmCAU accelerator (bring-up, TVLA and the same CPA non-recovery at a
comparable noise floor). Across the three target classes tested here, the right-angle connector and its
longer, differently-routed traces showed no effect this testing could measure; every metric agreed with the
standard board within the observed run-to-run variation.

## Reproducing these results

Everything needed to repeat this lives under `validation/`. Run each script in a Python 3.12 environment that
has `chipwhisperer` installed, for example `python validation/scripts/lab_2_1A.py`; the scripts prepend the
xpack ARM toolchain to `PATH` and use `PLATFORM=CW312_SAM4S`. These are working bench scripts, not a polished
package: they contain absolute paths from my own machine (the chipwhisperer repo and firmware locations, the
ARM toolchain directory, and in a few offline analysis scripts a local trace-cache path) and hard-code the
fixed AES key the ChipWhisperer demos use, so adjust those paths for your setup before running.

Bring-up and the `sca101` side-channel labs:

- [`validation/scripts/smoke_bringup.py`](validation/scripts/smoke_bringup.py): build, flash and capture the bring-up smoke test.
- [`validation/scripts/lab_2_1A.py`](validation/scripts/lab_2_1A.py): the Lab 2_1A instruction cost measurement.
- [`validation/scripts/lab_2_1B.py`](validation/scripts/lab_2_1B.py): the Lab 2_1B password bypass SPA attack.
- [`validation/scripts/lab_3_1.py`](validation/scripts/lab_3_1.py): the Lab 3_1 Hamming weight difference of means.
- [`validation/scripts/lab_3_3.py`](validation/scripts/lab_3_3.py): the Lab 3_3 DPA that recovers the full AES-128 key.
- [`validation/scripts/lab_4_2.py`](validation/scripts/lab_4_2.py): the Lab 4_2 CPA that recovers the full AES-128 key and plots convergence.

Fault injection (`fault101`):

- [`validation/scripts/fault_2_2_vglitch_find.py`](validation/scripts/fault_2_2_vglitch_find.py): the Fault 2_2 coarse search that first locates a voltage-glitch bypass.
- [`validation/scripts/fault_2_2_vglitch_bypass.py`](validation/scripts/fault_2_2_vglitch_bypass.py): the Fault 2_2 fine sweep that maps the bypass window.
- [`validation/scripts/fault_2_2_vglitch_lp.py`](validation/scripts/fault_2_2_vglitch_lp.py): the FILT_LP check (low-power crowbar crash rate vs glitch repeat).
- [`validation/scripts/vglitch_peakrate.py`](validation/scripts/vglitch_peakrate.py): peak-rate benchmark (best-cell search + 40-shot peak) used for the clean tee comparison.
- [`validation/scripts/vglitch_rate_robust.py`](validation/scripts/vglitch_rate_robust.py): the 200-shot batch-averaged bypass rate (five 40-shot batches) behind the 49.5% and 40.5% figures.
- [`validation/scripts/fault_2_3_memory_dump.py`](validation/scripts/fault_2_3_memory_dump.py): the Fault 2_3 voltage-glitch memory dump attack (with `fault_2_3_baseline.py`).
- [`fault_2_3_memory_dump.txt`](validation/evidence/fault_2_3_memory_dump.txt): hexdump of the leaked memory dump (601 bytes on the standard Abductor; the RA and CW313 dumps were 510 bytes; the length varies with the glitch).
- [`validation/scripts/clock_glitch_cw313_bypass.py`](validation/scripts/clock_glitch_cw313_bypass.py): clean clock-glitch password bypass on CW313 direct.
- [`validation/scripts/clock_glitch_abductor_repeat.py`](validation/scripts/clock_glitch_abductor_repeat.py): clock glitch via UFO+Abductor with increasing `repeat` (clean bypasses at repeat 4-16).
- [`validation/scripts/clock_glitch_characterize.py`](validation/scripts/clock_glitch_characterize.py), `validation/scripts/clock_glitch_cw313_isolation.py`: earlier clock-glitch parameter sweeps.

JTAG/SWD debug:

- [`validation/scripts/swd_debug.sh`](validation/scripts/swd_debug.sh): SWD halt and memory dump of the SAM4S via Husky MPSSE and OpenOCD (works on the CW313 and through the Abductor).
- [`validation/scripts/jtag_debug.sh`](validation/scripts/jtag_debug.sh): full JTAG version, reads the TAP IDCODE over TDI/TDO, then halts and reads memory.
- [`swd_cw313_dump.txt`](validation/evidence/swd_cw313_dump.txt), [`swd_abductor_dump.txt`](validation/evidence/swd_abductor_dump.txt): OpenOCD SWD readouts, the CW313 reference and through the Abductor.
- [`jtag_abductor_dump.txt`](validation/evidence/jtag_abductor_dump.txt): OpenOCD full-JTAG readout through the Abductor (TAP IDCODE, halt, memory).

Signal coverage and integrity:

- [`validation/scripts/signal_test.py`](validation/scripts/signal_test.py): flash a signal-test firmware and read the signal back over the CW (LED, GPIO3).
- [`validation/scripts/signal_integrity.py`](validation/scripts/signal_integrity.py): SNR (analyzer `calculate_snr`) plus fixed-vs-random TVLA t-test on the Abductor path.
- [`validation/scripts/firmware/led-blink/`](validation/scripts/firmware/led-blink/), `validation/scripts/firmware/abductor-sigtest/`: firmware sources for the LED and GPIO3/CLKOUT signal tests (build under `firmware/mcu/`).

iCE40 FPGA target:

- [`validation/scripts/ice40_hw_aes_cpa.py`](validation/scripts/ice40_hw_aes_cpa.py): hardware AES CPA on the CW312T-iCE40UP FPGA via the Abductor (last-round HD model, recovers the full key from 5000 traces; 3000 was the point this run first reached the full key, 5000 a safe margin).
- [`validation/scripts/dfa_selftest.py`](validation/scripts/dfa_selftest.py): offline proof of the DFA pipeline (software AES cross-checked against the FPGA's own ciphertext, then `phoenixAES` recovers the key from simulated round-9 and round-8 faults). No hardware needed.
- [`validation/scripts/ice40_dfa_phoenix.py`](validation/scripts/ice40_dfa_phoenix.py): the hardware DFA on the iCE40 via the Abductor (clock glitch, round-8 fault collection, `phoenixAES` crack, inverse key schedule to the master key); writes [`ice40_dfa_abductor.txt`](validation/evidence/ice40_dfa_abductor.txt).
- [`ice40_dfa_abductor.txt`](validation/evidence/ice40_dfa_abductor.txt), [`ice40_dfa_cw313.txt`](validation/evidence/ice40_dfa_cw313.txt): DFA evidence (collected round-8 faulty ciphertexts and the recovered round-10/master key, 16/16) for the Abductor and the CW313-direct reference.
- [`validation/scripts/ice40_sca_metrics.py`](validation/scripts/ice40_sca_metrics.py): leakage metrics for the iCE40 hardware AES via the Abductor (CPA convergence, full key at ~3000 traces this run, plus a fixed-vs-random TVLA t-test); saves `validation/img/ice40_cpa_convergence.png` and `validation/img/ice40_tvla.png`.

K82F hardware crypto accelerator:

- [`validation/scripts/k82f_flash.sh`](validation/scripts/k82f_flash.sh), `validation/scripts/k82f_bringup.py`: SWD flash (Husky MPSSE + OpenOCD `kx.cfg`) and known-answer bring-up of the CW312T-K82F hardware crypto accelerator. Firmware under `validation/scripts/firmware/k82f/` (mmCAU AES; LTC mask on / off / active for the DPA-mask study).
- [`validation/scripts/k82f_tvla.py`](validation/scripts/k82f_tvla.py): fixed-vs-random TVLA on the K82F mmCAU hardware AES (max |t|=100.6 Abductor, 65.8 CW313); saves `validation/img/k82f_tvla_*.png`.
- [`validation/scripts/k82f_cpa.py`](validation/scripts/k82f_cpa.py), `validation/scripts/k82f_leakcheck.py`, `validation/scripts/k82f_models.py`, `validation/scripts/k82f_mf_rigor.py`: the CPA effort on the mmCAU (blind, point-of-interest, matched-filter and 32-bit word models). The rigorous disjoint-set result (`k82f_mf_rigor.py`) shows the first-order CPA tried here did not recover the key; saves `validation/img/k82f_mmcau_cpa_convergence.png`. For completeness the repository also includes `k82f_cpa_break.py` and `k82f_mf_convergence.py`, which are deliberately *self-profiled* (the profile is built from the known key and scored on the same traces) and therefore report a false 16/16 by construction; they are kept only as the circular counter-example that the disjoint-set control corrects, and are not evidence of a key recovery.
- [`validation/scripts/k82f_compare.py`](validation/scripts/k82f_compare.py): the control experiment, identical 50k capture on the Abductor vs the CW313 baseboard, indicating the non-recovery is a property of the target, not the adapter.
- [`validation/scripts/k82f_mask_study.py`](validation/scripts/k82f_mask_study.py), `validation/scripts/k82f_mask_variance.py`: the LTC DPA-mask on/off study (inconclusive).

Reference and variant evidence:

- `validation/img/`: the generated figures.
- `validation/img/cw313/`, `validation/img/signal_integrity_cw313.png`, `validation/img/clock_glitch_cw313.png`, [`swd_cw313_dump.txt`](validation/evidence/swd_cw313_dump.txt), [`jtag_cw313_dump.txt`](validation/evidence/jtag_cw313_dump.txt): the CW313-direct reference evidence (see the results table above). Any script takes a `cw313` argument to save its output under `validation/img/cw313/`.
- `validation/img/ra/`, `validation/img/signal_integrity_ra.png`, [`fault_2_3_memory_dump_ra.txt`](validation/evidence/fault_2_3_memory_dump_ra.txt), [`swd_abductor_ra_dump.txt`](validation/evidence/swd_abductor_ra_dump.txt), [`jtag_abductor_ra_dump.txt`](validation/evidence/jtag_abductor_ra_dump.txt): the **Right-Angle Abductor** variant evidence. The SAM4S capture/lab/fault/signal scripts take an `ra` label argument to save figures under `validation/img/ra/` (for example `smoke_bringup.py ra`, `lab_3_3.py ra`, `signal_integrity.py ra`, `fault_2_2_vglitch_bypass.py ra`).
- [`ice40_dfa_ra.txt`](validation/evidence/ice40_dfa_ra.txt), `validation/img/ra/ice40_cpa_convergence.png`, `validation/img/ra/ice40_tvla.png`, `validation/img/k82f_tvla_ra.png`: the iCE40 and K82F evidence on the Right-Angle. The iCE40 scripts (`ice40_hw_aes_cpa.py`, `ice40_sca_metrics.py`, `ice40_dfa_phoenix.py`) and the K82F TVLA (`k82f_tvla.py`) take an `ra` label; `validation/scripts/k82f_ra_compare.py` captures a K82F set on the Right-Angle and compares its CPA non-recovery (byte-0 `|rho|`, blind, rigorous, noise) against the standard Abductor and CW313 caches.

## Notes and troubleshooting

Environment gotchas and the intermittent hardware quirks a rebuilder is likely to hit:

- **Python 3.12 in a venv:** the system ships Python 3.14, where chipwhisperer's pinned `numpy 1.26.4` has no
  3.14 wheels and did not build from source in this environment, so an isolated CPython 3.12 (via `uv`) is used
  instead.
- **Toolchain without sudo:** the ARM GCC toolchain is extracted under the home directory and its `bin` is
  prepended to `PATH` before running `make`.
- **USB permissions:** the stock NewAE udev rule assigns the `chipwhisperer` group and needs a re-login. It was
  switched to `plugdev` (already a member) for immediate access.
- **Lab 2_1A firmware note:** the serial response (`simpleserial_put`) was removed inside `get_pt()`, as the lab
  instructs, so the captured window reflects only the inserted instructions. The framework ack is still consumed
  (`ack=True`) so serial stays in sync.
- **SAM-BA flakiness:** on the AES labs one programming attempt returned a garbage ChipID, which was actually the
  running firmware's UART text leaking into the bootloader handshake (the SAM4S had not dropped into SAM-BA).
  Reconnecting the Husky USB cleared it and programming worked on the first try afterwards. This is the known
  intermittent SAM-BA handshake issue and is not specific to the Abductor; bring-up and Labs 2_1A and 2_1B
  flashed cleanly many times before it, and it also occurs on the standard board and the CW313.
- **SAM-BA pre-reset (memory dump):** flashing `bootloader-glitch` could hang the SAM-BA programmer when a
  previous test had left the SAM4S in a debug-halted or crashed state. Toggling `scope.io.nrst` low then high-Z
  just before `program_target` drops the SAM4S cleanly into its ROM bootloader and avoids the hang;
  `validation/scripts/fault_2_3_memory_dump.py` now does this. With that fix the CW313 memory dump landed a
  510-byte leak at the same `(width 2000, offset 2480, ext_offset 2122)` and a comparable first-success sweep
  position (near 2100 swept attempts) as the Abductor, so the crowbar fault path behaved the same on both.

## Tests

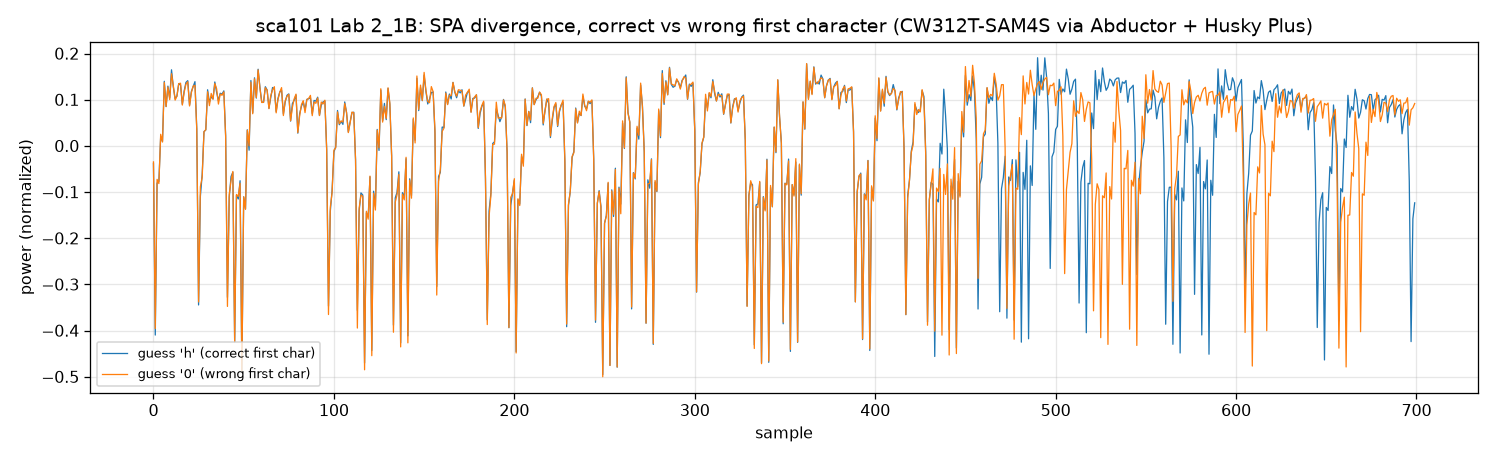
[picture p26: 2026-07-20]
validation/img/ra/2_1B_spa_divergence.png

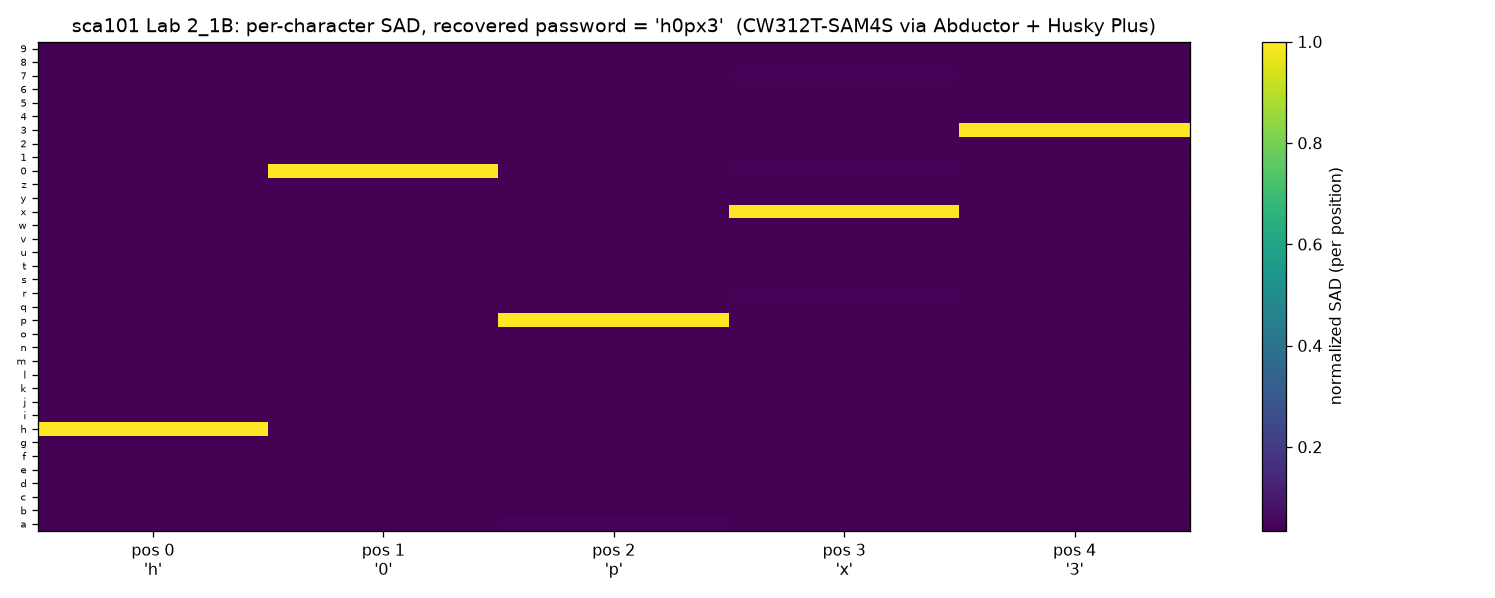
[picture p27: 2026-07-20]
validation/img/cw313/2_1B_attack_heatmap.png

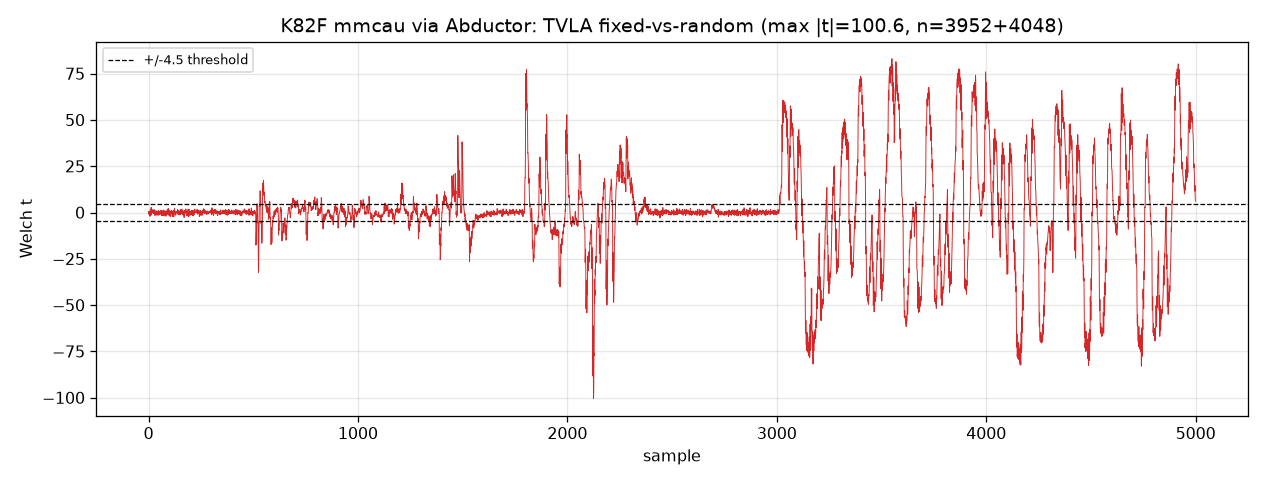
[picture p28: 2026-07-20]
validation/img/k82f_tvla_mmcau.png

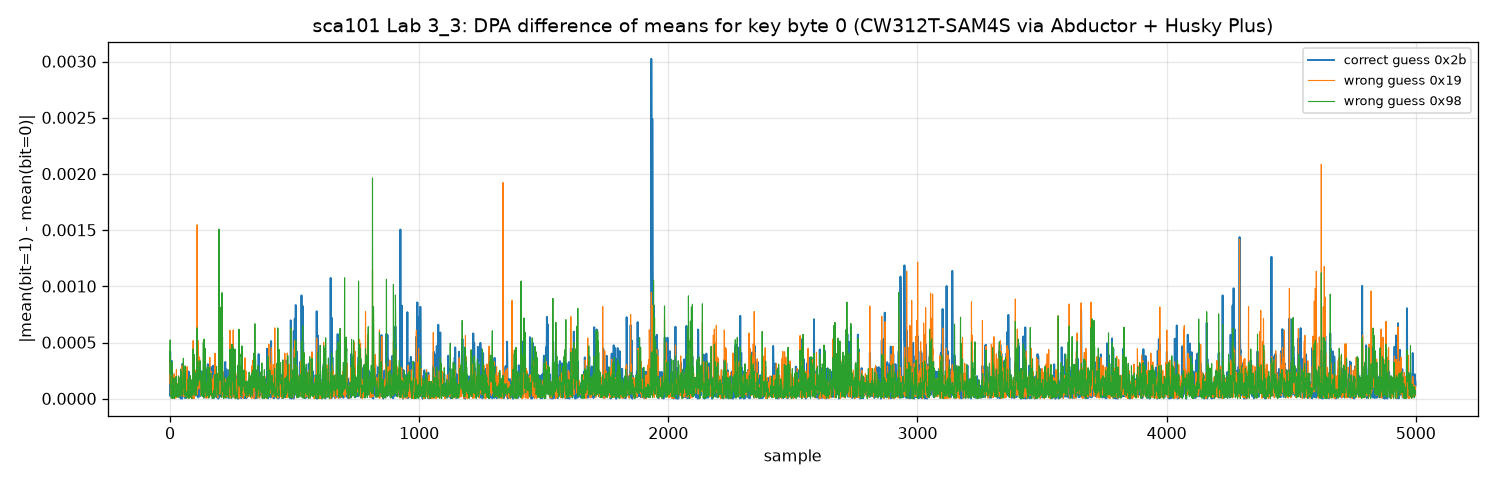
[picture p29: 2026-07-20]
validation/img/cw313/3_3_dpa_byte0.png

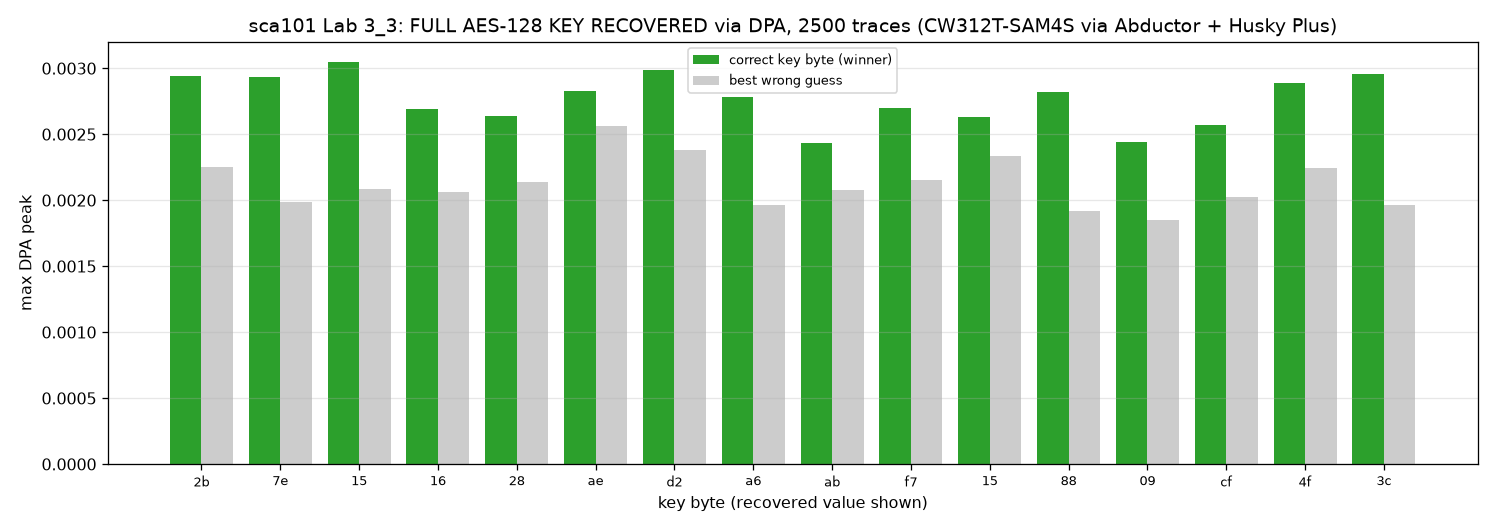
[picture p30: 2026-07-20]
validation/img/ra/3_3_dpa_result.png

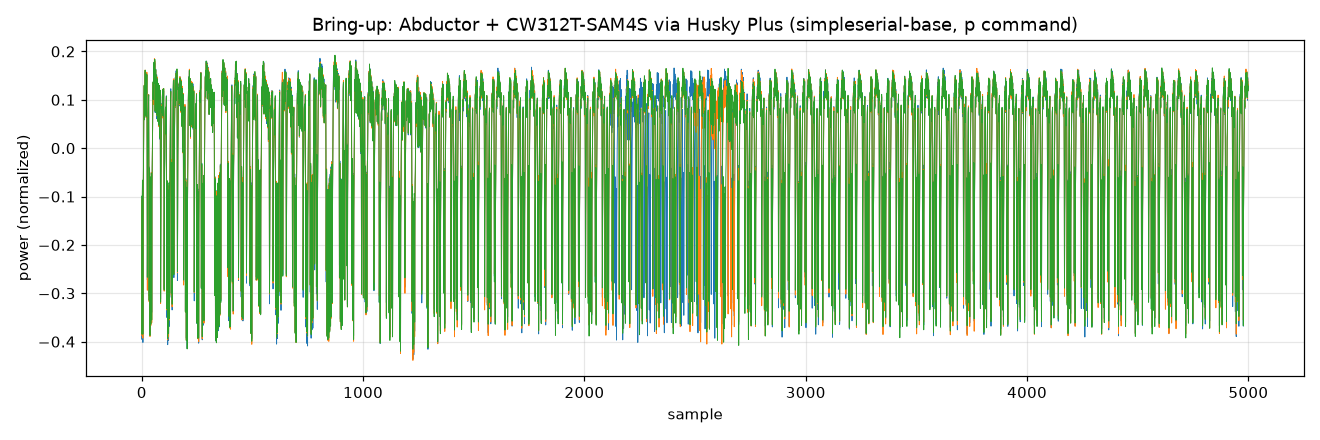
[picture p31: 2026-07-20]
validation/img/cw313/00_bringup_smoke_traces.png

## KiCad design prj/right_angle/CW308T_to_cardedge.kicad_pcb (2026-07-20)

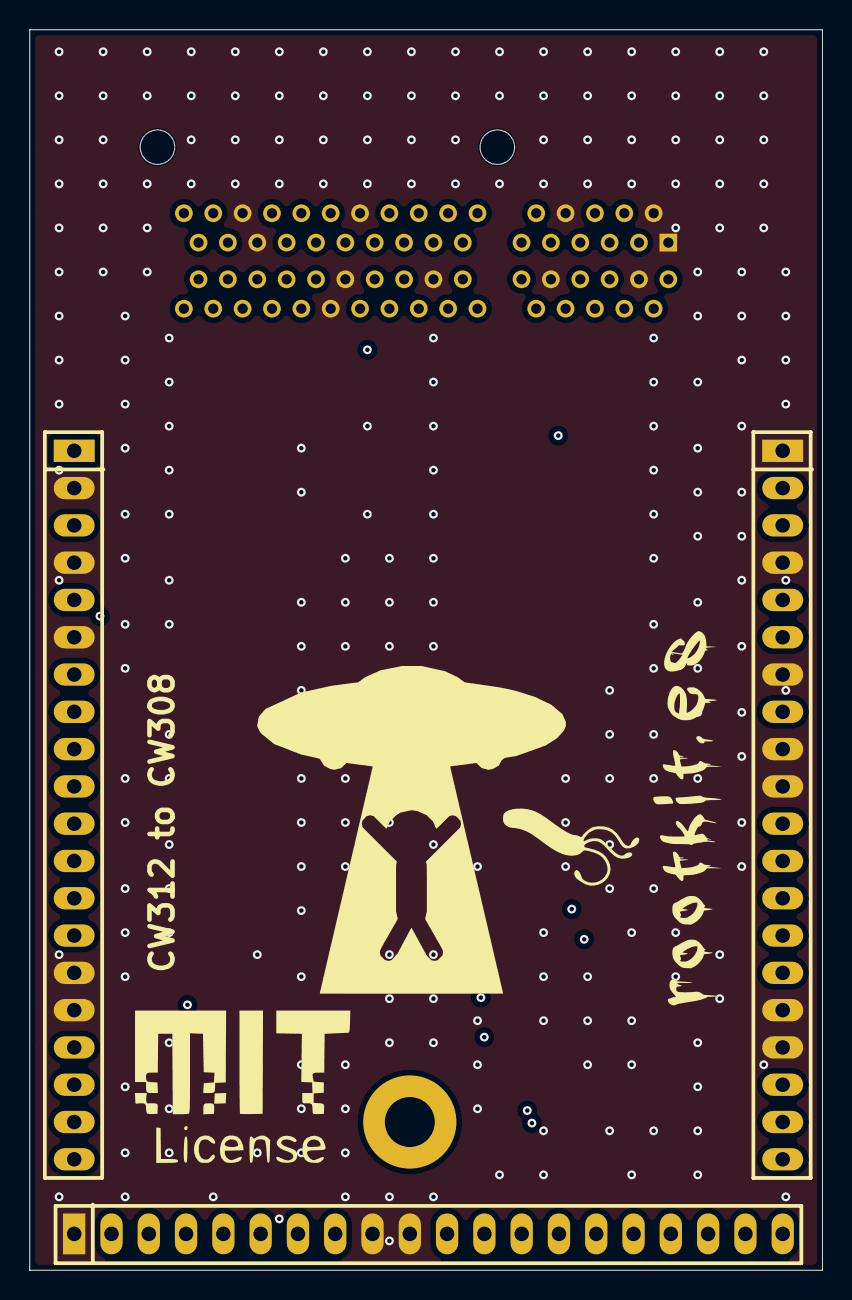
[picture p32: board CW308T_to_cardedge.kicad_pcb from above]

Board: 6 copper layers, 54.0 x 84.5 mm, 6 parts (1 on the bottom side), 44 nets.

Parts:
CN1: PCIE-064-02-F-D-RA; CONN-TH_64P-P1.00_PCIE-064-02-F-D-RA
G6566, G34434, G344333, G565656: LOGO
J1: CW308_TARGETCON; CW308_TBOARD_CONN

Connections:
/CLKIN: CN1.A29, J1.A5 (CLKIN(FROM_TARGET))
/CLKOUT: CN1.B27, J1.A3 (CLKOUT(TO_TARGET))
/FILTIN: CN1.B5, J1.C8 (FILTIN)
/FILT_HP: CN1.B4, J1.C6 (FILT_HP)
/FILT_LP: CN1.A3, J1.C5 (FILT_LP)
/GPIO1/TX: CN1.B16, J1.A7 (GPIO1)
/GPIO2/RX: CN1.B17, J1.A8 (GPIO2)
/GPIO3: CN1.B18, J1.A9 (GPIO3)
/GPIO4/TRIG: CN1.B19, J1.A10 (GPIO4)
/HDR1: CN1.A9, J1.B11 (HDR1)
/HDR2: CN1.A10, J1.B12 (HDR2)
/HDR3: CN1.A11, J1.B13 (HDR3)
/HDR4: CN1.A12, J1.B14 (HDR4)
/HDR5: CN1.A13, J1.B15 (HDR5)
/HDR6: CN1.A14, J1.B16 (HDR6)
/HDR7: CN1.A15, J1.B17 (HDR7)
/HDR8: CN1.A16, J1.B18 (HDR8)
/HDR9: CN1.A17, J1.B19 (HDR9)
/HDR10: CN1.A18, J1.B20 (HDR10)
/IOVREF: CN1.B10, J1.A20 (VREF)
/JTAG_TCK: CN1.B32, J1.B6 (JTAG_TCK)
/JTAG_TDI: CN1.B29, J1.B3 (JTAG_TDI)
/JTAG_TDO: CN1.B30, J1.B4 (JTAG_TDO)
/JTAG_TMS: CN1.B31, J1.B5 (JTAG_TMS)
/JTAG_TRST: CN1.A32, J1.B2 (JTAG_TRST)
/JTAG_VREF: CN1.A26, J1.B7 (JTAG_VREF)
/JTAG_nRST: CN1.A31, J1.B8 (JTAG_nRST)
/LED1: CN1.B11, J1.C18 (LED1)
/LED2: CN1.B12, J1.C19 (LED2)
/LED3: CN1.B13, J1.C20 (LED3)
/MISO: CN1.B23, J1.A13 (MISO)
/MOSI: CN1.B24, J1.A14 (MOSI)
/PDIC: CN1.B25, J1.A17 (PDIC)
/PDID: CN1.B26, J1.A18 (PDID)
/SCK: CN1.B20, J1.A12 (SCK)
/SHUNTH: CN1.B2, J1.C3 (SHUNTH)
/SHUNTL: CN1.B1, J1.C2 (SHUNTL)
/VCC1.2: CN1.B7, J1.C11 (VCC1.2V)
/VCC1.8: CN1.B8, J1.C12 (VCC1.8V)
/VCC2.5: CN1.A4, J1.C13 (VCC2.5V)
/VCC3.3: CN1.A5, J1.C14 (VCC3.3V)
/VCC5.0: CN1.A6, J1.C15 (VCC5.0V)
/nRST: CN1.B14, J1.A11 (nRST)
GND: CN1.A1, CN1.A2, CN1.A8, CN1.A20, CN1.A27, CN1.A28, CN1.B3, CN1.B9, CN1.B15, CN1.B21, CN1.B22, J1.A2 (GND), J1.A4 (GND), J1.A6 (GND), J1.A15 (GND), J1.A16 (GND), J1.B1 (GND), J1.B9 (GND), J1.B10 (GND), J1.C1 (GND), J1.C4 (GND), J1.C7 (GND), J1.C9 (GND), J1.C10 (GND), J1.C16 (GND), J1.C17 (GND)

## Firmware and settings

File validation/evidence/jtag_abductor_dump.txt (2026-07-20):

FULL JTAG (not just SWD) of the CW312T-SAM4S THROUGH the Abductor on the CW308 UFO.
Chain: Husky Plus MPSSE -> CW308 UFO -> Abductor -> CW312T-SAM4S.
This adds the two remaining debug data lines JTAG_TDI and JTAG_TDO on top of the SWD result,
so it exercises MOSI and MISO as well.

Non-DIO MPSSE (enable_MPSSE(1)); the Husky drives JTAG on the main 20-pin SPI/PDI pins.
Bridge on the CW308 UFO (6 wires): SWD 4 wires + 2 more for TDI/TDO:
  UFO SCK   -> J8 J_TCK   (JTAG_TCK)
  UFO PDID  -> J8 J_TMS   (JTAG_TMS)
  UFO MOSI  -> J8 J_TDI   (JTAG_TDI)   <- added for full JTAG
  UFO MISO  -> J8 J_TDO   (JTAG_TDO)   <- added for full JTAG
  UFO nRST  -> J8 nRST    (JTAG_nRST)
  UFO VREF  -> J8 J_UREF  (JTAG_VREF)
Husky Plus USB PID 0xace6. Transport: JTAG @ 200 kHz. OpenOCD 0.12.0.

Info : JTAG tap: sam4.cpu tap/device found: 0x4ba00477 (mfg: 0x23b (ARM Ltd), part: 0xba00, ver: 0x4)
Info : [sam4.cpu] Cortex-M4 r0p1 processor detected
Info : [sam4.cpu] target has 6 breakpoints, 4 watchpoints

--- JTAG scan chain ---
   TapName             Enabled  IdCode     Expected   IrLen IrCap IrMask
-- ------------------- -------- ---------- ---------- ----- ----- ------
 0 sam4.cpu               Y     0x4ba00477 0x4ba00477     4 0x01  0x0f
   ^ TAP IDCODE parallel-loaded in Capture-DR and shifted out on TDO (confirms TDO); TDI is exercised by the halt, flash and register reads below; matches expected.

[sam4.cpu] halted due to debug-request, current mode: Thread
xPSR: 0x01000000 pc: 0x0040061c msp: 0x200011a8

--- SAM4S CHIPID_CIDR @0x400E0740 ---
0x400e0740: 288b07e1

--- FLASH @0x00400000 (firmware vector table) ---
0x00400000: 200011a8 0040061d 00400619 00400619 00400619 00400619 00400619 00000000

--- CPU pc ---
pc = 0x0040061c

RESULT: full JTAG works through the Abductor. The IDCODE read confirms JTAG_TDO (MISO); the halt, flash and
register reads that follow confirm JTAG_TDI (MOSI), on top of the SWD-validated TMS/TCK/nRST/VREF.
Note: JTAG TAP IDCODE 0x4ba00477 differs from the SWD DP IDR 0x2ba01477, as expected (TAP IDCODE vs
SW-DP IDR); both identify the ARM Cortex-M4 debug port. The CW312T-SAM4S is NOT SWD-only; full JTAG
(TMS, TCK, TDI, TDO) passes through the adapter.

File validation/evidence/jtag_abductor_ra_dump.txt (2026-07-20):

=== enable Husky MPSSE (non-DIO) ===
MPSSE ON
=== OpenOCD JTAG: scan chain (TAP IDCODE) + halt + read ===
Info : JTAG tap: sam4.cpu tap/device found: 0x4ba00477 (mfg: 0x23b (ARM Ltd), part: 0xba00, ver: 0x4)
Info : [sam4.cpu] Cortex-M4 r0p1 processor detected
   TapName             Enabled  IdCode     Expected   IrLen IrCap IrMask
 0 sam4.cpu               Y     0x4ba00477 0x4ba00477     4 0x01  0x0f
Info : JTAG tap: sam4.cpu tap/device found: 0x4ba00477 (mfg: 0x23b (ARM Ltd), part: 0xba00, ver: 0x4)
[sam4.cpu] halted due to debug-request, current mode: Thread 
--- SAM4S CHIPID_CIDR @0x400E0740 ---
0x400e0740: 288b07e1 
--- FLASH @0x00400000 ---
0x00400000: 20001020 00400181 0040017d 0040017d 0040017d 0040017d 0040017d 00000000 
--- CPU pc ---
pc (/32): 0x00400180
=== disable MPSSE ===
MPSSE OFF

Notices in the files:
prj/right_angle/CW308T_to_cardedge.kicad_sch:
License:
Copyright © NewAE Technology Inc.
